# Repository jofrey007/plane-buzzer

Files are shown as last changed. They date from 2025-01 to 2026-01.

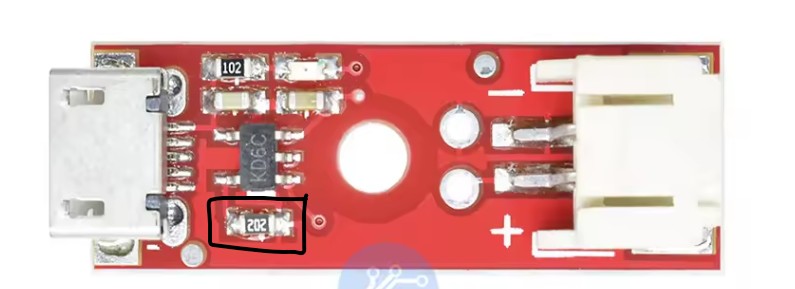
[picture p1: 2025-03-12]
hardware/charger.jpg

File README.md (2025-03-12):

## Determalizátor a bzučiak pre voľné modely
Princíp uvoľnenia pohyblivej časti modelu je cez prepálenie gumičky rozpáleným odporovým drôtom.
Determalizátor sa skladá z 2 modulov

 - prijímač 433 MHz s výkonovým MOSFET tranzistorom
 - modul bzučiaka s aktívnym piezzo bzučiakom

Napájanie determalizátora je LiPo akumulátorom 1S (3.7V), 35mAh, ktoré sa používajú do BT slúchadiel.

### Programovanie Attiny402
Pre naprogramovanie plane-buzzer.ino do MCU použite nejaké iné Arduino (Uno) ?
Popis programovania je uvedený v youtube videu aj s popisom pod ním
[Programovanie cez UPDI ](https://www.youtube.com/watch?v=YOGeoW_QySs)

### PCB bzučiaka

### Odporová špirála
3 závity na vrtáku 3mm [A1 30G 100Ft](https://www.aliexpress.com/item/1005001496323840.html?spm=a2g0o.order_list.order_list_main.284.61ee1802CS6hZ)

### Háčik na zavesenie gumy

### Anténa
Pôvodnú anténu odpájkovať a nahradiť rovnako dlhým vodičom [30AWG](https://www.aliexpress.com/item/1005001590476043.html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)

### Nabíjanie akumulátora
Akumulátor sa musí nabíjať malým prúdom okolo 5-10mA, z toho dôvodu je potrebné upraviť nabíjač s MCP73831. Úprava spočíva vo výmene SMD odporu za odpor s hodnotou 68k.
[nabíjačka](https://github.com/jofrey007/plane-buzzer/blob/main/hardware/charger.jpg)

## Galéria fotiek
[Google photos](https://photos.app.goo.gl/KZA55k8EkyTrNWjo8)

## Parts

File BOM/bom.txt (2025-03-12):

Vysielac
https://www.aliexpress.com/item/1005007015398402.html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
3,07
Prijimac
https://www.aliexpress.com/item/1005006650240831.html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
1,55
Bzuciak
https://www.aliexpress.com/item/1005006903202629.html?spm=a2g0o.order_list.order_list_main.5.2ab11802qtwSu5
0,36
Doska PCB (https://jlcpcb.com/)
0,50
MCU Attiny402 (TME)
1,20
Baterka 
https://www.aliexpress.com/item/1005006962050104.html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
0,80
Pin Header 1,27
0,5
Nabijac
https://www.aliexpress.com/item/1005002631037227.html?spm=a2g0o.order_list.order_list_main.75.36501802N0jKpt
1,99
Odpor nabijaca
0,1
Kabel vysielaca
0,2

Options (k nabijacke na nabijanie z LiPo clanku 2S/3S)
DC/DC z 12(8)V na 5V
https://www.aliexpress.com/item/10000000645877.html?spm=a2g0o.order_list.order_list_main.45.29e71802i3gj41
0,57
XT60
https://www.aliexpress.com/item/1005008582361773.html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
0,4
USB socket
https://www.aliexpress.com/item/1005007954649119.html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
0,35

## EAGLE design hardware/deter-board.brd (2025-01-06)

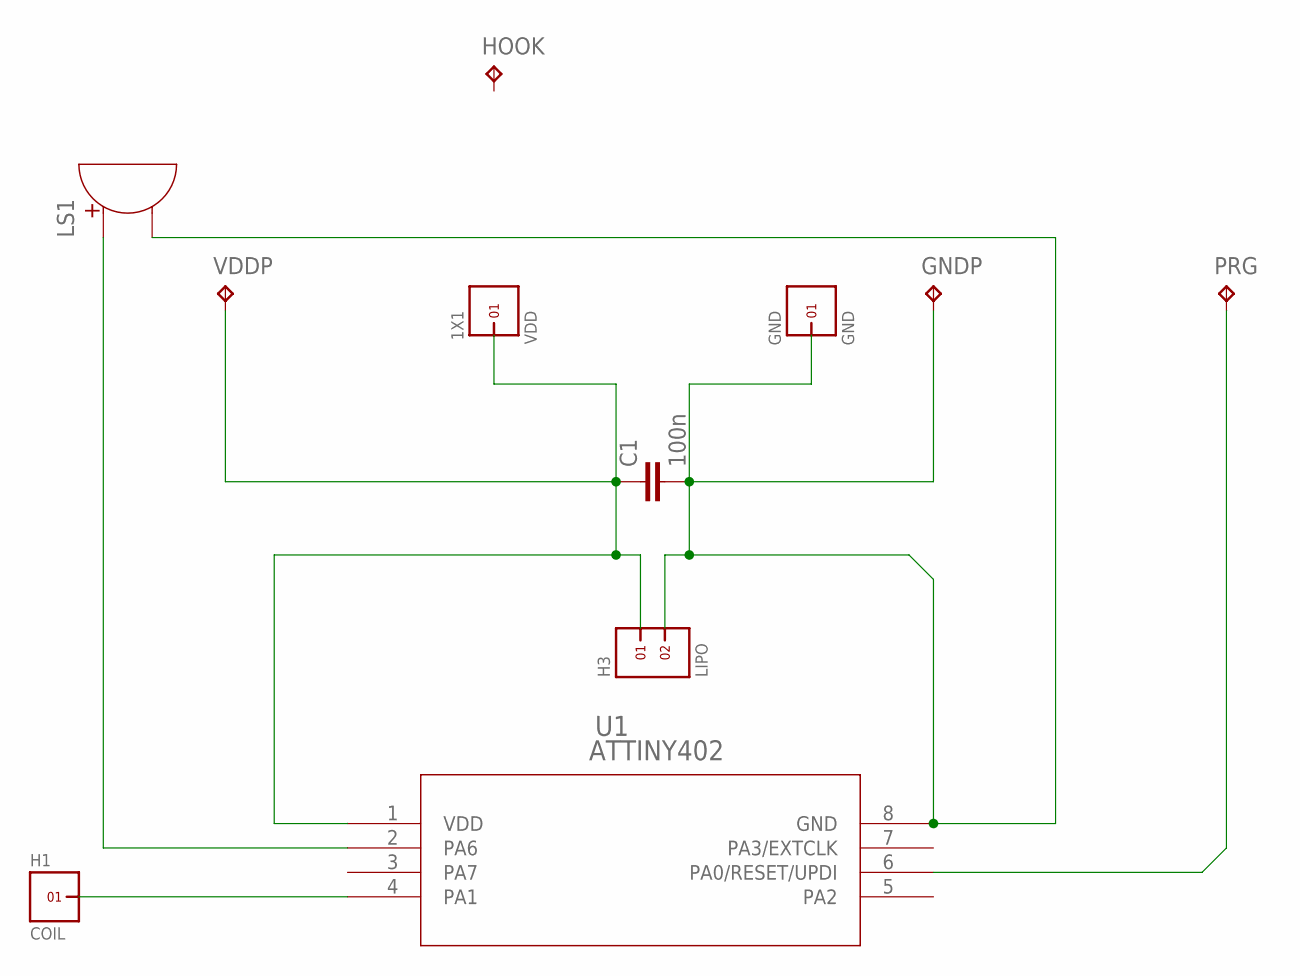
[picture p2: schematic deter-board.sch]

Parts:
C1: 100n; 1206
GND: GND; 1X1
GNDP: GND; B1,27
H1: COIL; 1X1
H3: LIPO; 1X2
HOOK: HOOK; P1-17Y
LS1: BUZZER_(9650); S-BUZZER-MLT-9650
PRG: PROG; B2,54
U1: ATTINY402; SOIC8_4P9X3P9MC_MCH
VDD: 1X1
VDDP: VDD; B1,27

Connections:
unnamed: LS1.P$2 (+), U1.2 (PA6)
unnamed: C1.1, H3.1, U1.1 (VDD), VDD.1, VDDP.TP
unnamed: C1.2, GND.1, GNDP.TP, H3.2, LS1.P$1 (-), U1.8 (GND)
unnamed: PRG.TP, U1.6 (PA0/RESET/UPDI)
unnamed: H1.1, U1.4 (PA1)

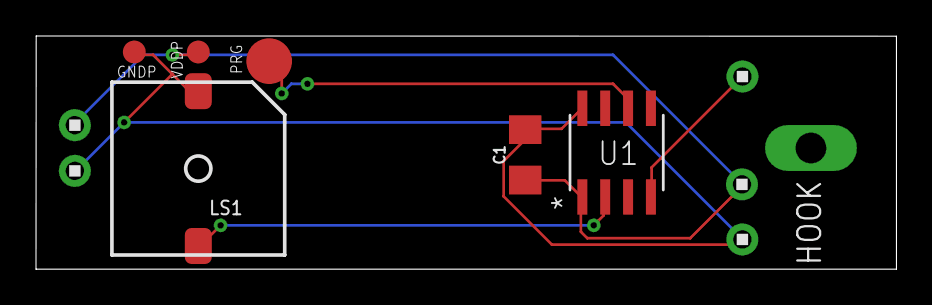
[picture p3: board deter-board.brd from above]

Board: 2 copper layers, 47.8 x 13.0 mm, 11 parts (0 on the bottom side), 5 nets.

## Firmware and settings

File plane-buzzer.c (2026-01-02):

/*
 * Determalizátor a bzučiak pre voľné modely
 * ATtiny402 - čistý C kód
 *
 * Optimalizovaná verzia pre minimálnu spotrebu energie
 */

#include <avr/io.h>
#include <avr/interrupt.h>
#include <avr/sleep.h>

#define BUZZER_PIN    PIN6_bm    // PA6, socket pin 2
#define TRIGGER_PIN   PIN1_bm    // PA1, socket pin 4

volatile uint8_t shouldBeep = 0;      // Príznak či má pípať
volatile uint8_t beepState = 0;       // 0 = ticho, 1 = pípanie
volatile uint8_t secondsCounter = 0;  // Počítadlo sekúnd

void disableUnusedPeripherals(void) {
    // Vypnutie nepoužívaných periférií pre úsporu energie
    TCA0.SPLIT.CTRLA = 0;
    ADC0.CTRLA &= ~ADC_ENABLE_bm;
    USART0.CTRLB &= ~(USART_RXEN_bm | USART_TXEN_bm);
    TWI0.CTRLA &= ~TWI_ENABLE_bm;
    SPI0.CTRLA &= ~SPI_ENABLE_bm;
    AC0.CTRLA &= ~AC_ENABLE_bm;        // Vypnúť komparátor
}

void setupBOD(void) {
    // BOD v sleep móde - sampled mód pre úsporu energie (~20µA)
    // Namiesto kontinuálneho monitorovania vzorkuje periodicky
    BOD.CTRLA = BOD_SLEEP_SAMPLED_gc;
}

void setupRTC(void) {
    // Počkať na synchronizáciu pred zápisom
    while (RTC.STATUS & RTC_CTRLABUSY_bm);

    // Použiť interný 32kHz oscilátor
    RTC.CLKSEL = RTC_CLKSEL_INT32K_gc;

    // Počkať na synchronizáciu PIT
    while (RTC.PITSTATUS & RTC_CTRLBUSY_bm);

    // Povoliť PIT prerušenie
    RTC.PITINTCTRL = RTC_PI_bm;

    // Zapnúť PIT s periódou 32768 cyklov = 1 sekunda
    RTC.PITCTRLA = RTC_PITEN_bm | RTC_PERIOD_CYC32768_gc;
}

void setupPins(void) {
    // Bzučiak ako výstup, začína v LOW
    PORTA.DIRSET = BUZZER_PIN;
    PORTA.OUTCLR = BUZZER_PIN;

    // Trigger ako vstup s prerušením na zostupnú hranu + pull-up
    PORTA.DIRCLR = TRIGGER_PIN;
    PORTA.PIN1CTRL = PORT_ISC_FALLING_gc | PORT_PULLUPEN_bm;

    // Nepoužívané piny ako výstupy v LOW (úspora energie)
    PORTA.DIRSET = PIN0_bm | PIN2_bm | PIN3_bm | PIN7_bm;
    PORTA.OUTCLR = PIN0_bm | PIN2_bm | PIN3_bm | PIN7_bm;

    // Vypnúť vstupné buffery na nepoužívaných pinoch (úspora ~1-5µA)
    PORTA.PIN0CTRL = PORT_ISC_INPUT_DISABLE_gc;
    PORTA.PIN2CTRL = PORT_ISC_INPUT_DISABLE_gc;
    PORTA.PIN3CTRL = PORT_ISC_INPUT_DISABLE_gc;
    PORTA.PIN6CTRL = PORT_ISC_INPUT_DISABLE_gc;  // BUZZER je výstup
    PORTA.PIN7CTRL = PORT_ISC_INPUT_DISABLE_gc;
}

// Prerušenie pri zmene stavu na TRIGGER pine
ISR(PORTA_PORT_vect) {
    if (PORTA.INTFLAGS & TRIGGER_PIN) {
        PORTA.INTFLAGS = TRIGGER_PIN;     // Vyčistiť príznak prerušenia
        shouldBeep = 1;                    // Povoliť pípanie
        beepState = 1;                     // Začať pípaním
        secondsCounter = 0;                // Vynulovať počítadlo
        PORTA.OUTSET = BUZZER_PIN;         // Zapnúť bzučiak
    }
}

// RTC PIT prerušenie - volá sa každú sekundu
ISR(RTC_PIT_vect) {
    RTC.PITINTFLAGS = RTC_PI_bm;          // Vyčistiť príznak prerušenia

    if (!shouldBeep) return;               // Ak nemá pípať, nič nerobiť

    secondsCounter++;                      // Zvýšiť počítadlo sekúnd

    if (beepState == 1) {                  // Ak pípa
        if (secondsCounter >= 1) {         // Po 1 sekunde
            PORTA.OUTCLR = BUZZER_PIN;     // Vypnúť bzučiak
            beepState = 0;                 // Prejsť do stavu ticha
            secondsCounter = 0;            // Vynulovať počítadlo
        }
    } else {                               // Ak je ticho
        if (secondsCounter >= 10) {        // Po 10 sekundách
            PORTA.OUTSET = BUZZER_PIN;     // Zapnúť bzučiak
            beepState = 1;                 // Prejsť do stavu pípania
            secondsCounter = 0;            // Vynulovať počítadlo
        }
    }
}

int main(void) {
    // Inicializácia v správnom poradí
    disableUnusedPeripherals();
    setupBOD();
    setupPins();
    setupRTC();

    // Povoliť globálne prerušenia
    sei();

    // Nastaviť sleep mód na POWER_DOWN (najnižšia spotreba)
    set_sleep_mode(SLEEP_MODE_PWR_DOWN);

    // Hlavná slučka - MCU spí a čaká na prerušenia
    while (1) {
        sleep_enable();
        sleep_cpu();
        sleep_disable();
    }

    return 0;
}

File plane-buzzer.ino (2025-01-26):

#include <avr/io.h>
#include <avr/interrupt.h>
#include <avr/sleep.h>
#include <util/delay.h>

#define BUZZER_PIN 0      // PA6, socket pin 2
#define TRIGGER_PIN 2     // PA1, socket pin 4

volatile bool shouldBeep = false;   // Príznak či má pípať
volatile uint8_t beepState = 0;     // 0 = ticho, 1 = pípanie
volatile uint8_t secondsCounter = 0; // Počítadlo sekúnd

void setupRTC() {
  RTC.CLKSEL = RTC_CLKSEL_INT32K_gc;  
  RTC.PITINTCTRL = RTC_PI_bm;         
  RTC.PITCTRLA = RTC_PITEN_bm | RTC_PERIOD_CYC32768_gc;  
  
  TCA0.SPLIT.CTRLA = 0; 
  ADC0.CTRLA &= ~ADC_ENABLE_bm;
  
  // Vypnutie nepoužívaných periférií
  USART0.CTRLB &= ~(USART_RXEN_bm | USART_TXEN_bm);
  TWI0.CTRLA &= ~TWI_ENABLE_bm;
  SPI0.CTRLB &= ~SPI_ENABLE_bm;
}

void setupPins() {
  pinMode(BUZZER_PIN, OUTPUT);
  digitalWrite(BUZZER_PIN, LOW);
  
  pinMode(TRIGGER_PIN, INPUT);
  PORTA.PIN1CTRL = PORT_ISC_FALLING_gc;  // Prerušenie na zostupnu hranu
//  PORTA.PIN1CTRL = PORT_ISC_RISING_gc;  // Prerušenie na nábežnú hranu
  
  // Nastavenie nepoužívaných pinov
  pinMode(1, OUTPUT);
  pinMode(3, OUTPUT);
  pinMode(4, OUTPUT);
  pinMode(5, OUTPUT);
}

// Prerušenie pri zmene stavu na pine
ISR(PORTA_PORT_vect) {
  if(PORTA.INTFLAGS & PIN1_bm) {
    PORTA.INTFLAGS = PIN1_bm;      // Vyčistiť príznak prerušenia
    shouldBeep = true;             // Povoliť pípanie
    beepState = 1;                 // Začať pípaním
    secondsCounter = 0;            // Vynulovať počítadlo
    digitalWrite(BUZZER_PIN, HIGH); // Zapnúť bzučiak
  }
}

// RTC prerušenie - volá sa každú sekundu
ISR(RTC_PIT_vect) {
  RTC.PITINTFLAGS = RTC_PI_bm;    // Vyčistiť príznak prerušenia
  
  if (!shouldBeep) return;         // Ak nemá pípať, nič nerobiť

  secondsCounter++;                // Zvýšiť počítadlo sekúnd
  
  if (beepState == 1) {           // Ak pípa
    if (secondsCounter >= 1) {     // Po 1 sekunde
      digitalWrite(BUZZER_PIN, LOW); // Vypnúť bzučiak
      beepState = 0;                // Prejsť do stavu ticha
      secondsCounter = 0;           // Vynulovať počítadlo
    }
  } else {                        // Ak je ticho
    if (secondsCounter >= 10) {    // Po 10 sekundách
      digitalWrite(BUZZER_PIN, HIGH);// Zapnúť bzučiak
      beepState = 1;                // Prejsť do stavu pípania
      secondsCounter = 0;           // Vynulovať počítadlo
    }
  }
}

void setup() {
  setupPins();
  setupRTC();
  sei();
}

void loop() {
  set_sleep_mode(SLEEP_MODE_PWR_DOWN);
  sleep_enable();
  sleep_cpu();
  sleep_disable();
}

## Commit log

2025-01-06 zmena nazvu suboru a pridanie suborov pre hardware
    [deter-board.brd, deter-board.sch]
2025-03-12 pridany BOM
2026-01-02 Prepis firmvéru do čistého C s optimalizáciami pre úsporu energie
    - Prepis z Arduino (.ino) do čistého C jazyka
    - Pridané optimalizácie pre minimálnu spotrebu:
    - Vypnutie vstupných bufferov na nepoužívaných pinoch
    - BOD v sampled móde počas sleep
    - Synchronizácia RTC registrov
    - Pull-up na TRIGGER pine
    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
2026-01-03 Pridaný flash.sh skript pre programovanie cez jtag2updi
    - Použitie Arduino Uno ako UPDI programátor
    - Automatická kontrola hex súboru a portu
    - Avrdude s jtag2updi protokolom

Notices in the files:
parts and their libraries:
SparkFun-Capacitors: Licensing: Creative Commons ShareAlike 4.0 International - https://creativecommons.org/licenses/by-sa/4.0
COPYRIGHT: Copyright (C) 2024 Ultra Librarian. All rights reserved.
